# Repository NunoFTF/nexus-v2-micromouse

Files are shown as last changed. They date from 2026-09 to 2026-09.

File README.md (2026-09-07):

# Nexus V2 — Autonomous Micromouse Robot

**Nexus V2** is a personal robotics project developed from **2023 to 2024** for the **Micromouse Portuguese Contest**. The robot uses a custom 2-layer PCB as its structural chassis and integrates power conversion, motor control, quadrature encoder feedback, infrared wall sensing, and an Arduino Nano RP2040 Connect.

The project covers the complete development cycle: electronic architecture, schematic capture, PCB layout, mechanical design, embedded firmware, control algorithms, system integration, and testing.

<p align="center">
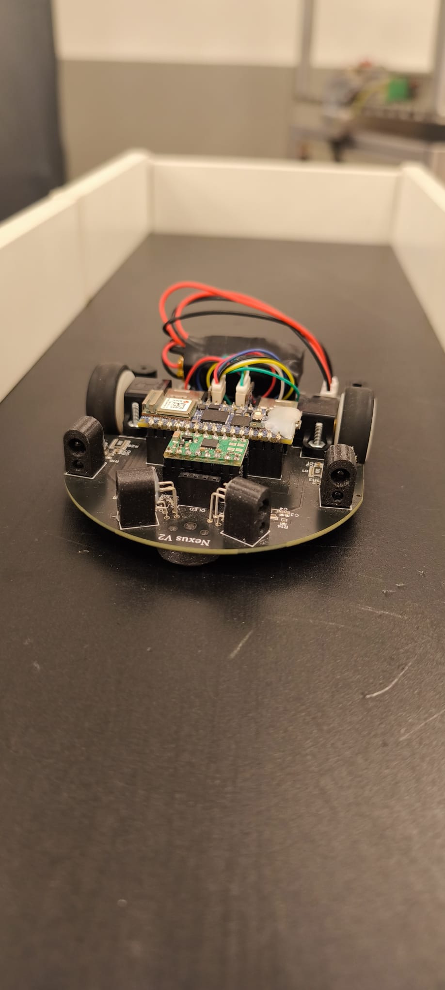
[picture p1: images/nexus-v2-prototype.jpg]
Nexus V2 assembled prototype
  
</p>

> **Project status:** Functional prototype. Closed-loop wheel-speed control, encoder-based odometry, 90°/180° turns, infrared wall detection, and autonomous wall-aware track navigation have been implemented. A complete maze-solving algorithm such as flood-fill is not yet implemented.

## Highlights

| Area | Implementation |
|---|---|
| Main controller | Arduino Nano RP2040 Connect |
| PCB | Custom 2-layer, 1.6 mm PCB; approximately 84 × 100 mm maximum envelope |
| PCB CAD | EasyEDA |
| Motor driver | Pololu DRV8833 dual motor driver carrier |
| Motors | 2 × Pololu 30:1 Micro Metal Gearmotor HPCB 6 V |
| Feedback | 2 × 12 CPR magnetic quadrature encoders |
| Wall sensing | 4 × custom IR channels using SFH4545 emitters and TEFT4300 phototransistors |
| Power | 2S LiPo; independent 6 V motor rail and 5 V logic rail using TPS562208 buck converters |
| Firmware | C++ using the Arduino framework |
| Control | Independent wheel PID speed control, differential-drive odometry and encoder-based turning |
| Mechanical CAD | Fusion 360 |
| Manufacturing | PCB manufactured and assembled by JLCPCB |

## What I Designed

This was an individual project. I was responsible for:

- System and electronic architecture
- Schematic design and component selection
- PCB layout and board outline
- Power architecture and motor-control integration
- Infrared sensing circuitry
- Embedded C++ firmware
- Quadrature encoder processing
- Wheel-speed PID control
- Odometry and motion control
- Autonomous wall-aware navigation logic
- Mechanical integration
- Custom wheel, sensor mount and slide-pad design
- Bring-up, calibration and system testing

## System Architecture

```mermaid
flowchart LR
    BAT[2S LiPo Battery]
    BUCK5[5 V Buck\nTPS562208]
    BUCK6[6 V Buck\nTPS562208]
    MCU[Arduino Nano\nRP2040 Connect]
    DRV[DRV8833\nMotor Driver]
    ML[Left Motor]
    MR[Right Motor]
    EL[Left Quadrature\nEncoder]
    ER[Right Quadrature\nEncoder]
    IRDRV[4 × MOSFET\nIR Emitter Drivers]
    IRS[4 × IR Sensor\nChannels]
    OLED[Optional I²C OLED]
    BUZZ[Buzzer]

    BAT --> BUCK5 --> MCU
    BAT --> BUCK6 --> DRV
    MCU --> DRV
    DRV --> ML
    DRV --> MR
    ML --> EL --> MCU
    MR --> ER --> MCU
    MCU --> IRDRV --> IRS --> MCU
    MCU --> OLED
    MCU --> BUZZ
```

## PCB and Mechanical Design

The PCB is not only an electronics carrier: it is also the **main structural chassis of the robot**. Its irregular outline was designed around the motor positions, sensor geometry and competition size constraints while giving the robot a compact car-like appearance.

The Arduino Nano RP2040 Connect and the DRV8833 carrier are socketed, allowing them to be removed during development or replacement. The board also integrates the motor/encoder connections, sensing electronics, power conversion, battery interface, buzzer and an I²C expansion connection for an OLED display.

<p align="center">
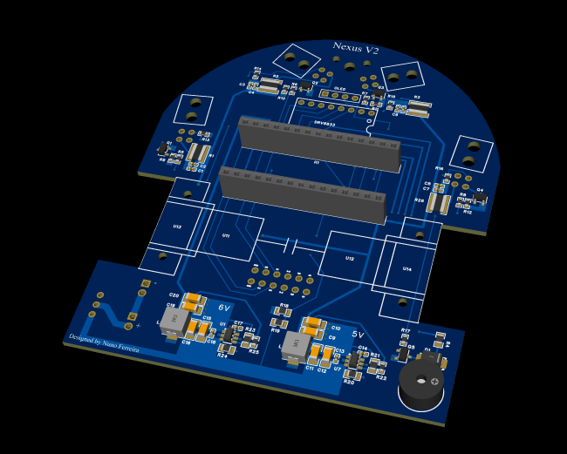
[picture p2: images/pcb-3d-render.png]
Nexus V2 PCB 3D render
  
</p>

<p align="center">
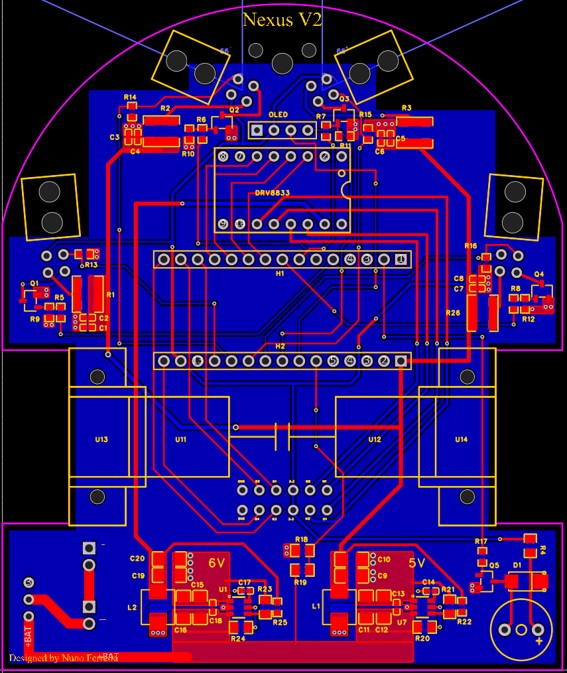
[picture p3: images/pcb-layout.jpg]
Nexus V2 PCB layout
  
</p>

The mechanical integration was designed in **Fusion 360**. The PCB itself forms the chassis, while several custom parts were created specifically for the robot:

- **20 mm wheel** designed to fit a separately sourced tyre
- **Sensor mount** for positioning the infrared sensing hardware
- **Low-friction slide pad** used as the front support instead of a third wheel

The two DC gearmotors are secured using **Pololu motor mounts**.

STEP files for the custom-designed mechanical parts are included in this repository.

## Infrared Wall Sensing

Nexus V2 uses four discrete reflective infrared sensor channels built from **SFH4545 IR emitters** and **TEFT4300 phototransistors**.

The sensor placement was chosen to provide complementary wall information:

- Two forward-mounted sensors are angled outward to measure the left and right side walls.
- Two sensors positioned further back face mostly forward, with a small angle that also helps detect corners in the cell ahead.

Each IR emitter is independently switched through a MOSFET. Rather than leaving the emitters permanently on, the firmware measures each channel in two stages:

1. Read the receiver with the IR emitter **off** to measure ambient light.
2. Turn the emitter **on**, wait briefly for settling and average multiple ADC samples.
3. Subtract the ambient reading from the illuminated reading.

This reduces sensitivity to ambient light. The four channels are sampled sequentially to reduce optical cross-talk between nearby emitters. Experimental calibration curves are then used to convert the differential ADC values into approximate distances.

## Encoder Processing and Odometry

Each motor uses a dual-channel magnetic quadrature encoder. Both encoder channels are processed using edge-triggered interrupts, allowing the firmware to determine both displacement and direction of rotation.

Encoder measurements are used to estimate individual wheel speed in **mm/s** and to calculate differential-drive odometry. The robot therefore estimates linear displacement and heading entirely from wheel feedback, without an IMU or gyroscope.

This encoder-based approach is also used to calibrate repeatable linear movements and in-place turns such as **90° and 180° rotations**.

## Closed-Loop Motion Control

Each wheel has an independent PID speed controller. Motion commands generate left and right wheel-speed setpoints in mm/s, and the controller continuously compensates for differences between the two motors.

For straight-line motion, both wheels receive the same nominal speed target while encoder feedback corrects speed mismatch. For in-place rotations, the two wheels are commanded in opposite directions and the turn is terminated using encoder-derived motion.

The firmware also uses side-wall measurements to modify the relative wheel speeds during wall following, helping keep the robot centred and preventing contact with the maze walls.

## Power Architecture

The robot is powered by two 300 mAh LiPo cells connected in series as a **2S battery pack**. Two independent TPS562208 buck converters generate:

- **6 V** for the DC motors
- **5 V** for the controller and sensors

The board also includes a main power switch and battery-voltage monitoring through an analog divider.

## Demonstrated Behaviour

The current prototype has been demonstrated autonomously on a test track. In the recorded demonstration, the robot:

1. Drives in a straight line under closed-loop speed control.
2. Uses the IR sensors together with encoder distance information to detect the end of the track.
3. Performs an in-place 180° turn.
4. Returns along the track.
5. Repeats the sequence autonomously.

The project has also reached autonomous wall-aware navigation without collisions. Full Micromouse maze mapping and flood-fill path planning remain future work.

## Demo

The Nexus V2 autonomously drives along the test track, detects the end of the path, performs an in-place 180° rotation, and returns along the track.

<p align="center">
  <a href="media/nexus-v2-demo.mp4">
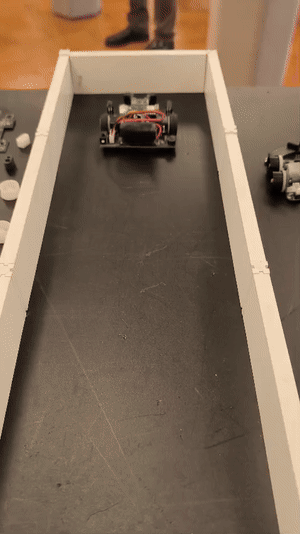
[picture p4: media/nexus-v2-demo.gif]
Nexus V2 autonomous demonstration
    
  </a>
</p>

<p align="center">
  <em>Click the animation to view the original video.</em>
</p>

## Design Files

- [Schematic PDF](docs/nexus-v2-schematic.pdf)
- EasyEDA schematic and PCB source files — to be added
- Mechanical STEP files:
  - [Wheel](mechanical/step/wheel.step)
  - [Sensor mount](mechanical/step/sensor-mount.step)
  - [Slide pad](mechanical/step/slide-pad.step)

> The firmware is currently being refined and is intentionally not included in the public portfolio version yet.

## Repository Structure

```text
nexus-v2-micromouse/
├── README.md
├── images/
│   ├── nexus-v2-prototype.jpg
│   ├── pcb-3d-render.png
│   └── pcb-layout.jpg
├── docs/
│   └── nexus-v2-schematic.pdf
├── mechanical/
│   └── step/
│       ├── wheel.step
│       ├── sensor-mount.step
│       └── slide-pad.step
└── media/
    ├── nexus-v2-demo.mp4
    └── nexus-v2-demo.gif
```

## Tools and Technologies

`EasyEDA` · `Fusion 360` · `Arduino C++` · `RP2040` · `PID Control` · `Quadrature Encoders` · `IR Sensing` · `Differential-Drive Odometry` · `JLCPCB`

---

**Designed and developed by Nuno**

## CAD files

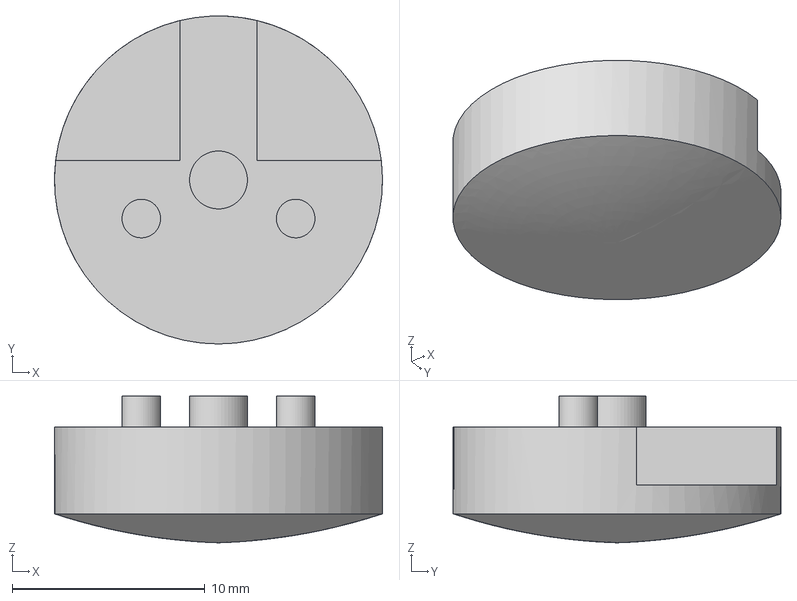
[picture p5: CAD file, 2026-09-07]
mechanical/step/slide-pad.step
17.0 x 17.0 x 7.60 mm

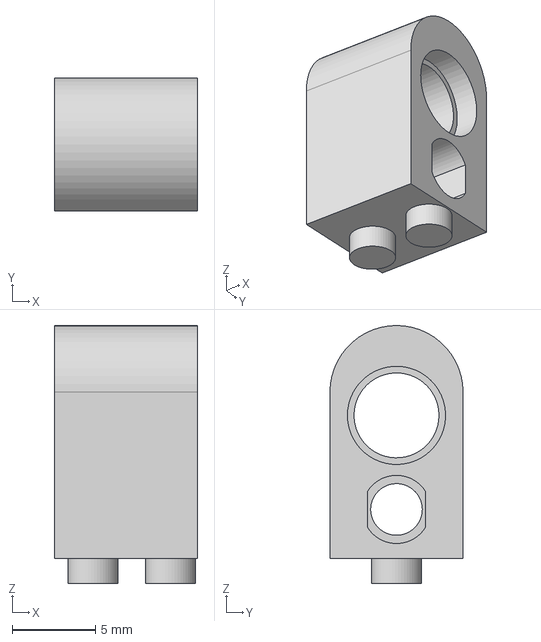
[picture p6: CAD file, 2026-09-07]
mechanical/step/sensor-mount.step
8.60 x 8.00 x 15.5 mm

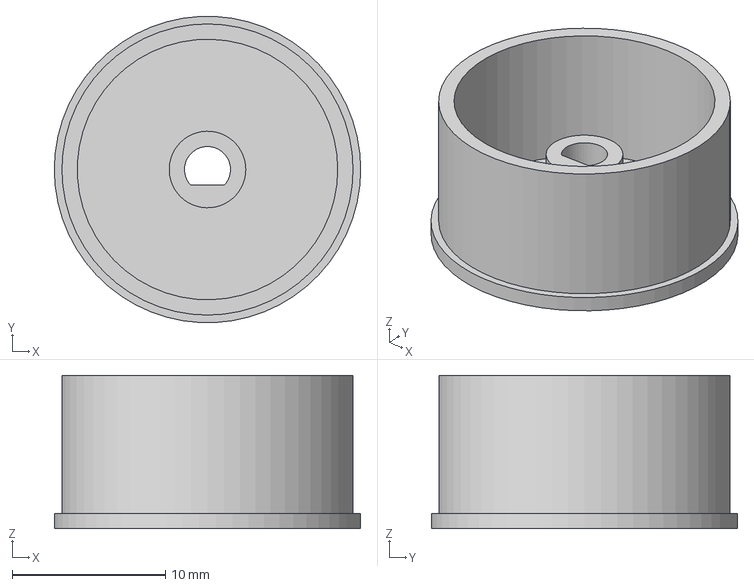
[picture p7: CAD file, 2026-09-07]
mechanical/step/wheel.step
20.0 x 20.0 x 10.0 mm

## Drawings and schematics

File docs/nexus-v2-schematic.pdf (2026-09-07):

### ARDUINO NANO RP2040

# Pololu DRV8833 ⁵V

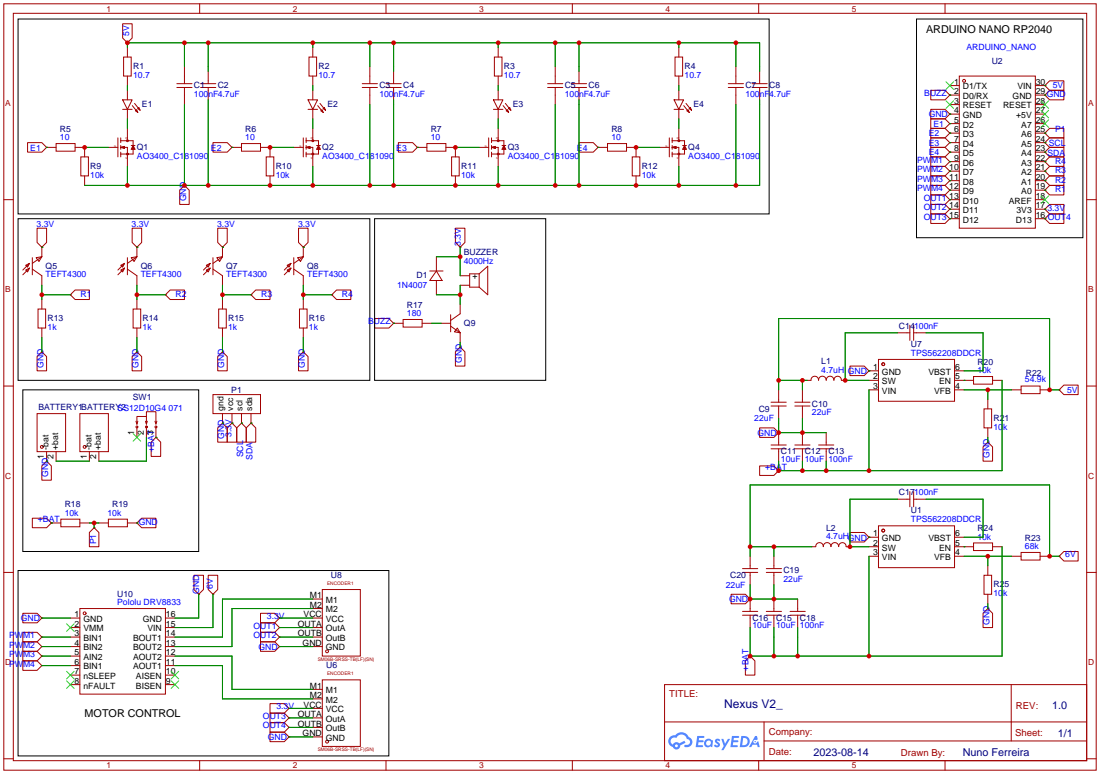
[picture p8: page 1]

SM06B-SRSS-TB(LF)(SN)
